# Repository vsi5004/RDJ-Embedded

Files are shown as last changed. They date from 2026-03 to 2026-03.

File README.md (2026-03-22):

# Vinyl Robot — EE & Firmware

Unified PCB design and STM32 firmware for a 5-node CANopen-based vinyl record handling robot.

## Documentation

- [System Architecture](docs/SYSTEM_ARCHITECTURE.md) — Mechanical overview, electrical architecture, safety layers
- [PCB Design](docs/PCB_DESIGN.md) — STM32G431 pin allocation, component selection, layout guidelines
- [Firmware Architecture](docs/FIRMWARE.md) — Bare-metal super-loop, CANopenNode integration, driver details
- [CANopen Protocol](docs/CANOPEN.md) — Object dictionary, PDO mapping, NMT lifecycle, bus analysis

## Hardware

- **MCU**: STM32G431CBU6 (UFQFPN48, 7×7mm)
- **Stepper driver**: TMC5160 stepstick (SPI motion controller mode)
- **CAN transceiver**: SN65HVD230
- **ToF sensors**: VL53L4CD (short range), VL53L1X (long range)
- **5 identical PCBs**, differentiated by populated components

## Development

Test-driven development with host-side unit tests (Unity framework, gcc). A HAL abstraction seam allows all driver and application logic to run on x86 with mock peripherals.

```bash
# Run all unit tests on host
make -C test/
```

See `docs/FIRMWARE.md` for the full TDD methodology, development phases, and HAL seam design.

## Prototyping

- Nucleo-G431RB for primary firmware development

## Related

ROS 2 control software lives in a separate repository. The CANopen object dictionary (EDS files) is the interface contract between firmware and ROS.

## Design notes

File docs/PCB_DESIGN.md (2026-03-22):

# PCB Design — Unified Controller Board

## MCU Selection

**STM32G431CBU6** (UFQFPN48, 7×7mm)

- Cortex-M4F @ 170MHz with FPU
- 128KB flash / 32KB RAM
- Native FDCAN peripheral
- 12-bit ADC with hardware 16× oversampling
- Multiple SPI, I2C, UART, timer peripherals
- Upgrade path: STM32G473CBU6 (same package, 256KB flash, 128KB RAM, pin-compatible)

### Why G431 over alternatives

- **vs STM32G0B1**: G0 has CAN-FD but Cortex-M0+ without FPU. ADC scaling and pot angle calculations benefit from FPU. Extra $2 is justified.
- **vs STM32F446**: G4 has native CAN-FD (not just CAN 2.0B) and better ADC oversampling.
- **vs RP2040**: No native CAN — would need external MCP2515 adding complexity and latency.
- **vs ESP32-S3**: TWAI (CAN 2.0B) works but FreeRTOS overhead is unnecessary for a dumb I/O node.

### Prototyping

Two Nucleo boards available:
- **Nucleo-G431RB** (LQFP64) — primary dev board, same silicon as G431CB
- **Nucleo-G474RE** (LQFP64) — backup/upgrade testing, 512KB flash

Pin remapping from Nucleo 64-pin to production 48-pin is a CubeMX regeneration — all peripherals in the allocation exist on both packages.

## Pin Allocation (21 of 37 usable GPIOs)

### SPI1 — TMC5160 Stepstick (4 pins)

| Pin | Function | Notes |
|-----|---|---|
| PA5 | SPI1_SCK | Stepstick clock |
| PA6 | SPI1_MISO | TMC5160 data out |
| PA7 | SPI1_MOSI | MCU data out |
| PA4 | SPI1_CS | Active low chip select |

The TMC5160 operates in full SPI motion controller mode. STEP/DIR pins on the stepstick are unused and remapped as REFL/REFR reference switch inputs. The optical endstop connects directly to the stepstick REFL pin — not to the MCU. StallGuard stop is enabled internally via the sg_stop bit in SWMODE. The EN pin on the stepstick header is tied permanently low (always enabled). Motor disable is done via SPI by writing TOFF=0 in CHOPCONF.

**This means the MCU's only connection to the stepper subsystem is 4 SPI pins.** Endstop, StallGuard, and enable are all handled by the TMC5160 internally. The MCU polls RAMPSTAT to learn about events after the fact.

### SPI2 — DotStar LEDs (2 pins)

| Pin | Function | Notes |
|-----|---|---|
| PB13 | SPI2_SCK | DotStar clock |
| PB15 | SPI2_MOSI | DotStar data (unidirectional) |

SPI2 is separate from SPI1 to avoid blocking TMC5160 reads during LED updates. DotStar frames are long (32 bits × up to 60 LEDs = 1920 bits) and would block SPI1 for ~50μs per update.

### FDCAN1 (2 pins)

| Pin | Function | Notes |
|-----|---|---|
| PA11 | FDCAN1_RX | From SN65HVD230 transceiver |
| PA12 | FDCAN1_TX | To SN65HVD230 transceiver |

### I2C1 — ToF Sensor (2 pins)

| Pin | Function | Notes |
|-----|---|---|
| PB8 | I2C1_SCL | 400kHz, 4.7kΩ pullups to 3.3V |
| PB9 | I2C1_SDA | VL53L4CD or VL53L1X at default 0x29 |

One ToF per board, one I2C bus per MCU — no address conflicts.

### TIM3 — RC Servo PWM (2 pins)

| Pin | Function | Notes |
|-----|---|---|
| PB4 | TIM3_CH1 | Servo 1 (grip/play) — 50Hz, 500–2500μs pulse |
| PB5 | TIM3_CH2 | Servo 2 (flip/speed) — 50Hz, 500–2500μs pulse |

On PB4/PB5 to avoid conflict with PA0 (ADC) on A axis board.

### ADC1 — Potentiometer (1 pin)

| Pin | Function | Notes |
|-----|---|---|
| PA0 | ADC1_IN1 | 10-turn pot, 16× hardware oversampling |

With 16× oversampling, effective resolution improves from 12-bit to ~16-bit. Over 300° of travel using ~8.3% of one turn, this gives approximately 0.05° effective resolution — adequate for the coarse homing application.

### USART2 — Debug UART (2 pins)

| Pin | Function | Notes |
|-----|---|---|
| PA2 | USART2_TX | Debug output, 115200 baud |
| PA3 | USART2_RX | Debug input |

Exposed on 3-pin JST-SH connector. Optional — can be omitted in production.

### SWD + Status (3 pins)

| Pin | Function | Notes |
|-----|---|---|
| PA13 | SWDIO | Tag-Connect TC2030 footprint |
| PA14 | SWCLK | Pogo-pin, no permanent connector |
| PB3 | GPIO out | Status LED — heartbeat toggle |

### Node ID DIP Switch (3 pins)

| Pin | Function | Notes |
|-----|---|---|
| PB0 | NODE_ID_0 | Internal pullup, switch to GND |
| PB1 | NODE_ID_1 | 3-bit = 8 addresses (5 used) |
| PB2 | NODE_ID_2 | Read once at boot |

PB0/PB1/PB2 are adjacent on the bottom edge of the LQFP48 package (pins 16/17/18), which is convenient for PCB routing.

PC13/PC14/PC15 are reserved for future use: PC14 (OSC32_IN) and PC15 (OSC32_OUT) for an optional LSE 32.768kHz crystal, and PC13 for RTC tamper/wakeup if an RTC is added. Neither is required by the current firmware — the IWDG uses the internal LSI and there is no RTC.

### Spare Pins (13 available)

PA1 (ADC — rail voltage monitoring), PA8 (TIM1 — buzzer), PA9/PA10 (USART1 — LiDAR passthrough if needed), PA15, PB6, PB7, PB10, PB11, PB12, PB14

## Population Matrix

| Component | X axis | Z axis | A axis | Pincher | Player |
|---|---|---|---|---|---|
| STM32G431CBU6 | ● | ● | ● | ● | ● |
| SN65HVD230 (CAN) | ● | ● | ● | ● | ● |
| 5V buck (3A) | ● | ● | ● | ● | ● |
| 3.3V LDO | ● | ● | ● | ● | ● |
| DIP switch (3-bit) | ● | ● | ● | ● | ● |
| TMC5160 stepstick socket | ● | ● | ● | ○ | ○ |
| Optical endstop connector | ● | ● | ● | ○ | ○ |
| ToF sensor connector (I2C) | ● | ● | ● | ● | ○ |
| Pot connector (ADC) | ○ | ○ | ● | ○ | ○ |
| Servo connectors (×2) | ○ | ○ | ○ | ● | ● |
| DotStar connector (SPI2) | ○ | ○ | ● | ○ | ● |
| 120Ω CAN termination jumper | ● | ○ | ○ | ○ | ● |

## PCB Layout Guidelines

- **Target board size**: ~50×40mm (similar to common stepper driver carriers)
- **Layers**: 2-layer, unbroken ground plane on bottom
- **Stepstick socket**: Standard 2×8 pin headers at 2.54mm pitch along one edge. Motor wires route away from signal traces.
- **Power entry**: 4-pin connector on one edge. 24V trace ≥1mm wide for 3A. Buck converter input/output caps close to IC.
- **CAN transceiver**: Between connector and MCU, near board edge. TVS diode (PESD2CAN) at connector pads.
- **Optional peripheral connectors**: JST-PH or JST-SH along remaining edges. 3-pin (VCC/GND/SIG) for simple sensors, 4-pin (VCC/GND/SCL/SDA) for I2C. Unpopulated variants leave connectors off.
- **SWD**: Tag-Connect TC2030 footprint (no permanent connector).
- **Do not let 24V trace split the ground plane.**

## Stepper Driver Selection

**TMC5160** in SPI motion controller mode (stepstick format).

The TMC5160's internal ramp generator handles all real-time step timing. The MCU sends target position, velocity, and acceleration parameters over SPI. The driver does the rest autonomously.

Key registers used:
- XTARGET: target position (written by MCU from CANopen RPDO)
- XACTUAL: current position (polled by MCU, reported in TPDO)
- VMAX, AMAX, DMAX: ramp parameters
- RAMPSTAT: status flags (position reached, stall detected, endstop hit)
- SWMODE: reference switch config (stop_l_enable for endstop, sg_stop for StallGuard)
- CHOPCONF: motor driver config (TOFF=0 to disable motor)
- SG_RESULT: StallGuard load measurement

### Stepstick compatibility note

Verify that the specific TMC5160 stepstick model remaps STEP/DIR pins as REFL/REFR when in SPI mode. Confirmed compatible: BTT TMC5160 V1.3, Watterott TMC5160 BOB. Some cheaper clones don't expose reference pins.

## Component Selection Summary

| Component | Part | Package | Notes |
|---|---|---|---|
| MCU | STM32G431CBU6 | UFQFPN48 | 128KB flash, M4F, FDCAN |
| CAN transceiver | SN65HVD230 | SOIC-8 | 3.3V, 1Mbit capable |
| CAN TVS | PESD2CAN | SOT-23 | Bidirectional TVS on CANH/CANL |
| 5V buck | MP2359 or TPS54331 | SOT-23-5/6 | 24V input, 3A output, for servos+LEDs |
| 3.3V LDO | AP2112K-3.3 | SOT-23-5 | 600mA, low dropout |
| ToF (short range) | VL53L4CD | module | 1–200mm, I2C, 18° FoV |
| ToF (long range) | VL53L1X | module | 4m max, I2C, programmable ROI |
| Status LED | 0603 green | 0603 | On PB3 via 470Ω |

## Flash Storage Layout

Last 4KB of 128KB flash reserved for persistent configuration:

| Address | Size | Purpose |
|---|---|---|
| 0x0801F000 | 2KB | Config slot A (active) |
| 0x0801F800 | 2KB | Config slot B (mirror) |

Double-buffer scheme: write new config to slot A, validate, then erase slot B. Next write goes to B, erase A. Atomic updates with power-loss protection. CANopenNode's OD_storage callback handles serialization.

Stored data per node: TMC5160 ramp defaults, StallGuard thresholds, pot calibration offset (A axis), node-specific config. ~256 bytes total. At 10,000 write cycle endurance, daily recalibration lasts 27 years.

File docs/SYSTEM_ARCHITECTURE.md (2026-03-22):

# Vinyl Robot — System Architecture

## Project Overview

An automated vinyl record handling robot that manages a queue of 5–6 records, picks them from a shelved stack, places them on a Pioneer PL-400 turntable, plays them, flips or swaps records, and returns them. The robot lives in a domestic living room environment with pets and humans nearby, requiring layered safety systems.

## Mechanical Architecture

The robot has a 1-meter linear stage (X axis) with two stations:
- **Left end (x=0)**: Shelved record queue stack — 5 slots with horizontal shelf floors between them, ~40mm pitch, ~20mm clearance per slot
- **Right end (x=1000mm)**: Pioneer PL-400 turntable connected to an audio system

### Axis Chain

**X axis (linear, 1000mm travel)** — Slides the entire upper assembly along a linear rail between the record stack and turntable. Driven by NEMA 17 stepper via TMC5160 in SPI motion controller mode.

**Z axis (vertical, ~150mm travel)** — Lead-screw driven vertical stage mounted on the X carriage. Lifts the end effector to clear the turntable platter and record stack shelves. Driven by NEMA 17 stepper via TMC5160.

**A axis (rotary, 300° travel)** — Belt-driven rotary stage mounted on the Z carriage. Rotates the pincher arm to reach records from different angles. Driven by NEMA 17 stepper via TMC5160. A 10-turn potentiometer provides coarse absolute position for safe homing on power-up. The pot is NOT used for closed-loop control — the TMC5160 microstep counter is the position authority during operation.

**Pincher (end effector)** — Two-jaw gripper that clamps a vinyl record from both sides. Driven by two RC servos: one for grip open/close, one for record flip (180° rotation). A VL53L4CD ToF sensor measures height above the surface below.

### Key Mechanical Constraints

- The record stack is a **shelved structure** with floors between slots. When the arm is inside a slot, Z movement is dangerous in both directions — shelves above and below with only ~20mm clearance.
- The A axis has physical hard stops at 0° and 300° to protect the cable wrap.
- The turntable is an open surface — Z up is always safe when near it.
- Furniture and walls constrain the A axis safe rotation window (configurable, default 30°–330°).

## Electrical Architecture

### Power Distribution

- **24V input** from a power supply in the robot base
- 24V rail routed through the full axis chain to each controller board
- Each board has:
  - 24V → TMC5160 VM (motor power) directly
  - 24V → 5V buck converter (3A, for servos and DotStar LEDs)
  - 5V → 3.3V LDO (MCU, CAN transceiver, sensors)

### CAN Bus

- Single CAN 2.0B bus at 1Mbit/s
- 5 nodes + SBC master
- 120Ω termination at both physical ends (X axis board and Player Control board) via solder jumpers
- SN65HVD230 transceivers on each node
- TVS protection (PESD2CAN) at each node's connector
- 4-pin connectors per board: 24V, GND, CANH, CANL

### Controller Boards

Five identical PCBs differentiated by populated components. See [PCB_DESIGN.md](./PCB_DESIGN.md) for full details.

| Node ID | Board | Populated Peripherals |
|---|---|---|
| 0x01 | X axis | TMC5160, endstop on stepstick, VL53L1X ToF |
| 0x02 | Z axis | TMC5160, endstop on stepstick, VL53L4CD ToF |
| 0x03 | A axis | TMC5160, endstop on stepstick, VL53L4CD ToF, 10-turn pot (ADC), DotStar ring (20 LEDs) |
| 0x04 | Pincher | 2× RC servos (grip + flip), VL53L4CD ToF |
| 0x05 | Player Control | 2× RC servos (play/stop + speed), DotStar strip (~1m, along X rail) |

### SBC (System on Module)

**Toradex Verdin iMX8M Plus (4GB RAM)** on **Mallow carrier board**

Selected for:
- Native dual CAN-FD (FlexCAN) — no USB adapter needed
- Gigabit Ethernet for SICK TIM571 LiDAR
- MIPI-CSI camera interface with ISP
- 2.3 TOPS NPU for future CV upgrades
- Industrial temp range and long-term availability
- Torizon OS with Docker-based ROS 2 deployment

### Sensors

**LiDAR**: SICK TIM571-2050101 (preferred) — 270° FoV, 15Hz, Ethernet TCP/IP. Mounted on top of Z column. Acts as a safety curtain.

**Camera**: USB or CSI camera for tonearm position tracking on the turntable. 640×480 @ 15fps is sufficient.

**ToF sensors**:
- X axis: VL53L1X (long range, 25mm–1000mm, focused beam via ROI) — startup collision avoidance
- Z axis: VL53L4CD (short range, 10–150mm, ±1mm) — height confirmation
- Pincher: VL53L4CD — height above surface below for grip confirmation
- All on I2C, one per board, no address conflicts

**Potentiometer**: 10-turn pot on A axis belt drive. Read via MCU ADC with 16× hardware oversampling. Used only for:
1. Coarse absolute angle on power-up (±2° accuracy, enough for safe homing direction)
2. Runtime sanity check against TMC5160 XACTUAL (every few seconds, ±5° divergence triggers EMCY)

## Safety Architecture (Layered)

| Layer | Mechanism | Response Time | Catches |
|---|---|---|---|
| 1 — Mechanical | Current limits on TMC5160, rubber bumpers, A axis hard stops | Instant | Force limits on all failures |
| 2 — StallGuard | TMC5160 sg_stop bit — driver stops motor internally | ~1ms | Collisions with objects, pets, humans |
| 3 — LiDAR | SICK TIM571 → ROS safety node → CAN halt | ~100ms | Humans approaching the robot |
| 4 — Watchdog | CAN heartbeat (100ms) + ROS lifecycle monitoring | 200–500ms | Software crashes, bus faults, node lockups |
| 5 — E-stop | Hardware power cut to 24V motor rail (relay/contactor) | Instant | Everything else |

## Software Architecture

### Firmware (this repo)

All five controller boards run the same firmware binary (STM32 bare-metal + CANopenNode). Behavior is selected by DIP switch node ID at boot. MCUs are dumb I/O nodes — no operational logic, no motion planning, no state machines. They receive commands and report status.

See [FIRMWARE.md](./FIRMWARE.md) and [CANOPEN.md](./CANOPEN.md) for details.

### ROS 2 (separate repo)

ROS 2 Humble on Torizon OS (Docker container). 7 nodes: CANopen master, motion coordinator, LiDAR safety, turntable monitor, state machine (BehaviorTree.CPP), LED controller, diagnostics.

All operational intelligence lives on the SBC. The SBC knows the mechanical geometry, safety zones, homing sequences, and the full record-handling workflow.

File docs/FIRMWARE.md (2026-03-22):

# Firmware Architecture

## Overview

All five controller boards run the same firmware binary. Behavior is selected by the 3-bit DIP switch (node ID) read at boot. The firmware is a bare-metal super-loop with CANopenNode as the communication stack. There is no RTOS. MCUs are dumb I/O nodes — they receive commands over CAN, actuate peripherals, read sensors, and report status. All operational intelligence lives on the SBC.

## Development Methodology — Test-Driven

All firmware modules are developed test-first. Unit tests run on the host machine (x86, gcc) without any target hardware. A thin HAL abstraction seam separates driver logic from STM32 register access. Driver code is identical on host and target — only the lowest-level HAL implementation differs.

**Test framework**: Unity (single-header C test framework). Mocks are hand-written — the HAL seam is thin enough that auto-generation (CMock) is unnecessary.

**Development cycle for each module**:
1. Write failing tests that define the expected behavior
2. Implement the driver/module to pass the tests
3. Run `make -C test/` to verify (builds and runs in under a second)
4. Flash to Nucleo for hardware validation

**Development phase order** (each builds on the previous):

| Phase | Tests | Module | Validates |
|---|---|---|---|
| 1 | Register r/w, target, status, StallGuard, init | `drv_tmc5160.c` | SPI protocol, bit packing, all register access |
| 2 | RPDO staging, SYNC application, TPDO latching, status word | `app_canopen.c` | Two-stage staging, atomic SYNC, status bits |
| 3 | Homing state machine, pot direction, endstop zero | `app_homing.c` | Per-axis homing, A axis pot logic |
| 4 | Fault detection, fault-blocks-motion, clear-fault, EMCY | fault paths in `app_canopen.c` | EMCY generation, status word, recovery |
| 5 | ToF ranging, servo clamping, DotStar framing | `drv_tof.c`, `drv_servo.c`, `drv_dotstar.c` | I2C protocol, PWM limits, LED format |
| 6 | Node config macros, flash roundtrip, corruption recovery | `node_config.h`, `cfg_flash.c` | Population logic, double-buffer integrity |

## Build System and Project Structure

Two build targets from the same source tree:
- **Target build**: arm-none-eabi-gcc / STM32CubeIDE — produces the binary for the STM32G431
- **Test build**: host gcc — compiles driver logic + mocks + Unity, runs on x86

```
firmware/
├── Core/                        # CubeMX generated HAL init (target only)
├── Drivers/                     # STM32 HAL + CMSIS (target only)
├── Lib/
│   └── CANopenNode/             # git submodule
├── App/
│   ├── hal/                     # Hardware abstraction seam
│   │   ├── hal_spi.h            # SPI interface (function pointer struct)
│   │   ├── hal_spi_stm32.c      # Real STM32 implementation (target only)
│   │   ├── hal_i2c.h
│   │   ├── hal_i2c_stm32.c
│   │   ├── hal_adc.h
│   │   ├── hal_adc_stm32.c
│   │   ├── hal_pwm.h
│   │   ├── hal_pwm_stm32.c
│   │   ├── hal_gpio.h
│   │   ├── hal_gpio_stm32.c
│   │   ├── hal_can.h
│   │   ├── hal_can_stm32.c
│   │   └── hal_flash.h
│   ├── drv/                     # Drivers — pure logic, testable on host
│   │   ├── drv_tmc5160.c        # SPI register r/w, ramp config, StallGuard
│   │   ├── drv_tmc5160.h
│   │   ├── drv_tof.c            # I2C ranging start/read (non-blocking)
│   │   ├── drv_tof.h
│   │   ├── drv_servo.c          # PWM pulse width control
│   │   ├── drv_servo.h
│   │   ├── drv_dotstar.c        # SPI2 LED frame output
│   │   └── drv_dotstar.h
│   ├── app/                     # Application logic — testable on host
│   │   ├── app_main.c           # Super-loop, boot sequence
│   │   ├── app_canopen.c        # OD definition, PDO callbacks, NMT hooks
│   │   ├── app_canopen.h
│   │   ├── app_homing.c         # Per-axis homing state machine
│   │   ├── app_homing.h
│   │   ├── cfg_flash.c          # Double-buffer flash config storage
│   │   └── node_config.h        # Node ID → peripheral enable mapping
│   └── OD/
│       ├── OD.h                 # Generated from EDS or hand-written
│       └── OD.c
├── test/                        # Host-side unit tests (x86, gcc)
│   ├── unity/                   # Unity test framework (vendored or submodule)
│   │   ├── unity.c
│   │   └── unity.h
│   ├── mocks/                   # Mock HAL implementations for testing
│   │   ├── mock_spi.c           # Records SPI writes, returns controlled data
│   │   ├── mock_spi.h
│   │   ├── mock_i2c.c
│   │   ├── mock_i2c.h
│   │   ├── mock_adc.c
│   │   ├── mock_adc.h
│   │   ├── mock_can.c
│   │   ├── mock_pwm.c
│   │   ├── mock_gpio.c
│   │   └── mock_flash.c
│   ├── test_tmc5160.c           # TMC5160 SPI driver tests
│   ├── test_canopen_pdo.c       # PDO staging + SYNC application tests
│   ├── test_homing.c            # Homing state machine tests
│   ├── test_fault.c             # Fault detection and EMCY tests
│   ├── test_tof.c               # ToF sensor I2C tests
│   ├── test_servo.c             # Servo PWM tests
│   ├── test_dotstar.c           # DotStar LED tests
│   ├── test_node_config.c       # Node ID mapping tests
│   ├── test_flash.c             # Flash double-buffer tests
│   └── Makefile                 # Builds and runs all tests on host
├── Makefile                     # Target build (arm-none-eabi-gcc)
└── vinyl_robot.ioc              # STM32CubeMX project
```

## HAL Abstraction Seam

The seam between testable logic and hardware is a struct of function pointers for each peripheral:

```c
// hal/hal_spi.h
typedef struct {
    int (*transfer)(uint8_t *tx, uint8_t *rx, uint16_t len);
} hal_spi_t;

extern hal_spi_t hal_spi1;  // Global instance — real or mock
```

On target, `hal_spi_stm32.c` sets the function pointer to the real STM32 HAL call. In tests, `mock_spi.c` provides a version that records what was transmitted and returns controlled responses.

Drivers accept the HAL instance at init and never include STM32 headers directly:

```c
// drv/drv_tmc5160.c
#include "drv_tmc5160.h"
#include "hal_spi.h"

static hal_spi_t *spi;

void tmc5160_init(hal_spi_t *spi_instance) {
    spi = spi_instance;
}

void tmc5160_write_register(uint8_t reg, uint32_t value) {
    uint8_t tx[5] = {
        reg | 0x80,
        (value >> 24) & 0xFF,
        (value >> 16) & 0xFF,
        (value >> 8) & 0xFF,
        value & 0xFF
    };
    uint8_t rx[5];
    spi->transfer(tx, rx, 5);
}
```

The `UNIT_TEST` preprocessor flag (set by the test Makefile, not by the target build) guards any remaining target-specific includes:

```c
#ifndef UNIT_TEST
#include "stm32g4xx_hal.h"
#endif
```

## Test Build

```bash
# Run all tests (from repo root)
make -C test/

# Run a single test suite
make -C test/ test_tmc5160 && test/test_tmc5160

# Clean
make -C test/ clean
```

The test Makefile compiles driver sources + mock HAL + Unity + test files with host gcc. Each test binary runs independently and exits with 0 on pass, non-zero on failure. Total test execution is under 1 second.

## Node Configuration

```c
// App/app/node_config.h
#define NODE_HAS_TMC(id)    ((id) >= 1 && (id) <= 3)
#define NODE_HAS_SERVO(id)  ((id) >= 4)
#define NODE_HAS_TOF(id)    ((id) != 5)
#define NODE_HAS_POT(id)    ((id) == 3)
#define NODE_HAS_LED(id)    ((id) == 3 || (id) == 5)
```

## Boot Sequence

```
1. HAL_Init() — clocks to 170MHz via HSI/PLL, SysTick
2. Read DIP switch (PC13/14/15) → node_id
3. Conditional peripheral init based on node_id:
   - if (node_id <= 0x03)  init_spi1_tmc5160();
   - if (node_id == 0x03)  init_adc_pot();
   - if (node_id == 0x03 || node_id == 0x05)  init_spi2_dotstar();
   - if (node_id >= 0x04)  init_pwm_servos();
   - if (node_id != 0x05)  init_i2c_tof();
4. load_config_from_flash(node_id);
5. CO_init() — start CANopenNode stack, enter NMT pre-operational
6. Start IWDG (100ms timeout)
7. Enter main super-loop
```

## Main Super-Loop

```c
while (1) {
    // 1. Service CANopen stack
    CO_process();  // NMT, SDO, heartbeat, emergency — ~5-20μs

    // 2. On SYNC callback (set by ISR flag)
    if (sync_received) {
        latch_tpdo_data();      // Copy sensor readings into TPDO buffers
        apply_queued_rpdo();    // Write staged commands to actuators
        sync_received = false;
    }

    // 3. TMC5160 polling (stepper nodes only)
    if (NODE_HAS_TMC(node_id)) {
        tmc5160_poll();  // Read XACTUAL, RAMPSTAT, SG_RESULT via SPI ~30μs
        if (rampstat_has_event()) {
            update_status_word();
            if (stallguard_triggered() || unexpected_endstop()) {
                send_emcy();
            }
        }
    }

    // 4. Sensor polling (10Hz, triggered by TIM7 flag)
    if (sensor_poll_flag) {
        if (NODE_HAS_TOF(node_id))  tof_read_distance();   // I2C ~100μs
        if (NODE_HAS_POT(node_id))  pot_read_angle();       // ADC register read
        if (NODE_HAS_LED(node_id))  dotstar_update();       // SPI2 if pattern changed
        sensor_poll_flag = false;
    }

    // 5. Servo update (servo nodes only)
    if (NODE_HAS_SERVO(node_id) && servo_target_changed) {
        servo_update_pwm();  // Write TIM3 CCR registers
        servo_target_changed = false;
    }

    // 6. Watchdog and diagnostics
    IWDG_kick();
    toggle_status_led();  // Heartbeat blink
    if (NODE_HAS_POT(node_id))  pot_sanity_check();  // Compare pot vs XACTUAL
}
```

Worst-case loop iteration: ~400μs → natural loop rate ~2.5kHz, well above 50Hz SYNC.

## Interrupt Context

Minimal — ISRs set flags, all heavy work in main loop.

| ISR | Handler | Purpose |
|-----|---|---|
| FDCAN1_IT0 | CO_CANinterrupt() | CAN frame reception, CANopenNode processing |
| SysTick | HAL_IncTick() + CO timing | 1ms tick for HAL delays and CANopenNode timers |
| TIM7 | Set sensor_poll_flag | 10Hz trigger for ToF/pot/LED polling |

**Design rule**: ISRs set flags only. All SPI, I2C, and CAN TX happen in the main loop. No peripheral bus access from ISR context.

## TMC5160 SPI Driver (App/drv/drv_tmc5160)

The driver communicates with the TMC5160 via SPI1 at 4MHz. All register access is 40-bit transactions (8-bit address + 32-bit data). The driver uses the `hal_spi_t` abstraction — it never touches STM32 HAL directly, making it fully testable on the host.

### Key Operations

```c
// Write a register
void tmc5160_write(uint8_t reg, uint32_t value);

// Read a register (returns 32-bit value, requires two transactions)
uint32_t tmc5160_read(uint8_t reg);

// Configure motion parameters
void tmc5160_set_target(int32_t position);   // Write XTARGET
void tmc5160_set_velocity(uint32_t vmax);    // Write VMAX
void tmc5160_set_accel(uint16_t amax, uint16_t dmax);  // Write AMAX, DMAX
void tmc5160_set_rampmode(uint8_t mode);     // 0=position, 1=velocity+, 2=velocity-

// Read status
int32_t tmc5160_get_position(void);          // Read XACTUAL
uint32_t tmc5160_get_rampstat(void);         // Read RAMPSTAT
uint16_t tmc5160_get_stallguard(void);       // Read SG_RESULT

// Motor control
void tmc5160_disable(void);  // Write TOFF=0 in CHOPCONF
void tmc5160_enable(void);   // Restore TOFF from config
```

### Initialization Sequence

```c
void tmc5160_init(void) {
    // 1. Write GCONF — enable SPI mode, internal ramp generator
    // 2. Write CHOPCONF — set TOFF, HSTRT, HEND for motor tuning
    // 3. Write IHOLD_IRUN — set run current, hold current, hold delay
    // 4. Write SWMODE — enable stop_l_enable (endstop), sg_stop (StallGuard)
    // 5. Write SGTHRS — StallGuard threshold (from flash config)
    // 6. Write VMAX, AMAX, DMAX — default ramp parameters (from flash config)
    // 7. Write RAMPMODE = 0 — position mode
    // 8. Write XACTUAL = 0 — assume unhomed
}
```

### Homing (Stepper Nodes)

Homing is initiated by the SBC setting the "home" bit in the control word (OD 0x2004). The MCU runs the homing sequence locally:

**X and Z axes:**
1. Set TMC5160 to velocity mode at slow speed, toward endstop
2. TMC5160 hits endstop on REFL → stops internally (SWMODE stop_l_enable)
3. MCU reads XACTUAL, writes it to zero
4. Set status word "homed" bit
5. Return to position mode

**A axis:**
1. Read pot via ADC → determine which direction is shortest path to endstop
2. Set TMC5160 to velocity mode toward endstop in that direction
3. TMC5160 hits endstop → stops
4. Zero XACTUAL
5. Set "homed" bit

The SBC orchestrates the ORDER of homing (which axis homes first, moving to safe zones between steps). But the actual endstop-seek-and-zero on each individual axis is handled by the MCU firmware.

## RPDO/TPDO Callback Pattern

CANopenNode uses callbacks for OD entry writes. The firmware implements a two-stage staging pattern:

1. **RPDO write callback**: Copy received value into a shadow buffer. Set "pending" flag. Do NOT actuate yet.
2. **SYNC callback**: If pending flag is set, copy shadow buffer to live target. Execute actuation (SPI write to TMC5160, or PWM update for servos). Clear pending flag.

This ensures:
- Multi-field commands (target + velocity + accel) all apply atomically on the same SYNC
- No partial updates if the master sends fields across multiple CAN frames
- SYNC-gated start for coordinated multi-axis moves

## Fault Handling

When a fault is detected (StallGuard, unexpected endstop, sensor timeout, SPI failure):

1. Set fault bit in status word (OD 0x2003)
2. Send CANopen EMCY frame with error code
3. Hold current position (don't disable motor — maintain holding torque)
4. Ignore new motion commands until fault is cleared
5. Wait for SBC to send clear-fault via control word (OD 0x2004)

### EMCY Error Codes

| Code | Meaning |
|---|---|
| 0x2100 | StallGuard triggered |
| 0x2200 | Unexpected endstop hit (not during homing) |
| 0x2300 | ToF reading out of expected range |
| 0x2400 | Pot vs XACTUAL divergence exceeds 5° (A axis) |
| 0x2500 | TMC5160 SPI communication failure |
| 0x2600 | Servo position feedback timeout |
| 0x5000 | CAN bus-off recovery |

## FDCAN Configuration

CAN 2.0B (classic CAN) at 1Mbit/s with 170MHz PCLK1:

- Prescaler: 10
- Time segment 1: 13
- Time segment 2: 3
- Sync jump width: 1
- → 17 time quanta per bit, 76.5% sample point

Two RX filters:
1. Accept standard frames matching node ID range (SDO, NMT directed)
2. Accept broadcast frames (SYNC, NMT broadcast, emergency)

## Development Notes

### Getting CANopenNode Running First

Before adding any motion code, get the CANopen stack running in isolation:
1. Init FDCAN with correct bit timing
2. Init CANopenNode with minimal OD (just mandatory objects)
3. Verify heartbeat visible on CAN bus (use Nucleo + CAN transceiver breakout)
4. Test SDO read/write of a single OD entry from a second Nucleo or PC with CAN adapter
5. Then add TMC5160 SPI driver, sensors, etc. incrementally

FDCAN filter configuration and timing register setup are the most common gotchas on STM32G4.

### StallGuard Tuning

StallGuard sensitivity needs different thresholds for:
- **Homing**: Very sensitive (high SGTHRS) — moving slowly with no load, any resistance = obstacle
- **Normal operation**: Less sensitive — carrying a record adds load, shouldn't false-trigger
- **Near turntable**: May need adjusted sensitivity due to different friction characteristics

Log SG_RESULT values during normal operations to find the threshold window. Store per-node thresholds in flash config. The SBC can adjust via SDO during operation if needed.

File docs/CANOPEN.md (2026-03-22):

# CANopen Protocol Specification

## Network Configuration

- **Bus speed**: 1Mbit/s CAN 2.0B (classic CAN, not CAN-FD)
- **SYNC period**: 20ms (50Hz), broadcast by SBC master
- **Heartbeat producer**: 100ms interval on all nodes
- **Heartbeat consumer**: SBC detects node loss within 200ms (2 missed heartbeats)
- **SDO timeout**: 500ms
- **Termination**: 120Ω at node 0x01 (X axis) and node 0x05 (Player) — solder jumper on PCB

## Node Addressing

| Node ID | Board | DIP Switch | CAN ID Range (hex) |
|---|---|---|---|
| 0x01 | X axis | 001 | TPDO: 0x181, RPDO: 0x201, SDO TX: 0x581, SDO RX: 0x601 |
| 0x02 | Z axis | 010 | TPDO: 0x182, RPDO: 0x202, SDO TX: 0x582, SDO RX: 0x602 |
| 0x03 | A axis | 011 | TPDO: 0x183, RPDO: 0x203, SDO TX: 0x583, SDO RX: 0x603 |
| 0x04 | Pincher | 100 | TPDO: 0x284, RPDO: 0x304, SDO TX: 0x584, SDO RX: 0x604 |
| 0x05 | Player | 101 | TPDO: 0x285, RPDO: 0x305, SDO TX: 0x585, SDO RX: 0x605 |

SYNC COB-ID: 0x080 (broadcast)
NMT COB-ID: 0x000 (broadcast)
Heartbeat COB-ID: 0x700 + node_id

## Object Dictionary

### Mandatory CANopen Objects (all nodes)

| Index | Sub | Type | Name | Default |
|---|-----|---|---|---|
| 0x1000 | 0 | UINT32 | Device type | 0x000F0191 |
| 0x1001 | 0 | UINT8 | Error register | 0x00 |
| 0x1017 | 0 | UINT16 | Producer heartbeat time (ms) | 100 |
| 0x1018 | 1 | UINT32 | Vendor ID | TBD |
| 0x1018 | 2 | UINT32 | Product code | TBD |
| 0x1018 | 3 | UINT32 | Revision number | firmware version |

### Common Application Objects (all nodes)

| Index | Sub | Type | Name | Access | Notes |
|---|-----|---|---|---|---|
| 0x2000 | 0 | UINT8 | Node role | RO | Read from DIP switch at boot |
| 0x2001 | 0 | UINT16 | Firmware version | RO | Major.minor packed |
| 0x2002 | 0 | UINT16 | Board temperature | RO | Internal ADC, °C × 10 |
| 0x2003 | 0 | UINT8 | Status word | RO | See bit definitions below |
| 0x2004 | 0 | UINT8 | Control word | RW | See bit definitions below |
| 0x2005 | 0 | UINT32 | Uptime (ms) | RO | Since boot |

#### Status Word (0x2003) Bit Definitions

| Bit | Name | Description |
|-----|---|---|
| 0 | homed | Axis has been homed since boot |
| 1 | moving | Ramp generator is active (RAMPSTAT velocity ≠ 0) |
| 2 | in_position | Target position reached (RAMPSTAT position_reached) |
| 3 | fault | Fault active — motion commands ignored |
| 4 | homing | Currently executing homing sequence |
| 5 | stallguard_active | StallGuard monitoring enabled |
| 6–7 | reserved | |

#### Control Word (0x2004) Bit Definitions

| Bit | Name | Description |
|-----|---|---|
| 0 | enable | Enable motor driver (write TOFF in CHOPCONF) |
| 1 | home | Start homing sequence |
| 2 | halt | Emergency halt — decelerate to stop |
| 3 | clear_fault | Clear fault state, resume normal operation |
| 4–7 | reserved | |

### Motion Objects — Stepper Nodes (0x01, 0x02, 0x03)

| Index | Sub | Type | Name | Access | Notes |
|---|-----|---|---|---|---|
| 0x2100 | 0 | INT32 | Target position | RW | Microsteps → TMC5160 XTARGET |
| 0x2101 | 0 | INT32 | Actual position | RO | TMC5160 XACTUAL |
| 0x2102 | 0 | UINT32 | Max velocity (pps) | RW | → TMC5160 VMAX |
| 0x2103 | 0 | UINT16 | Acceleration | RW | → TMC5160 AMAX |
| 0x2104 | 0 | UINT16 | Deceleration | RW | → TMC5160 DMAX |
| 0x2105 | 0 | UINT8 | Ramp status | RO | TMC5160 RAMPSTAT bits |
| 0x2106 | 0 | UINT16 | StallGuard result | RO | TMC5160 SG_RESULT |
| 0x2107 | 0 | UINT16 | ToF distance (mm) | RO | VL53L reading |
| 0x2108 | 0 | UINT8 | Ramp mode | RW | 0=position, 1=velocity+, 2=velocity- |

### A Axis Extras (node 0x03 only)

| Index | Sub | Type | Name | Access | Notes |
|---|-----|---|---|---|---|
| 0x2200 | 0 | INT16 | Pot angle (0.1° units) | RO | Coarse absolute — homing + sanity check |
| 0x2220 | 0 | UINT32 | LED pattern | RW | DotStar ring state |

### Servo Objects — Pincher (0x04) and Player (0x05)

| Index | Sub | Type | Name | Access | Notes |
|---|-----|---|---|---|---|
| 0x2300 | 0 | UINT16 | Servo 1 position (μs) | RW | Pulse width 500–2500μs |
| 0x2301 | 0 | UINT16 | Servo 2 position (μs) | RW | Pulse width 500–2500μs |
| 0x2302 | 0 | UINT16 | ToF distance (mm) | RO | Pincher only |
| 0x2310 | 0 | UINT32 | LED pattern | RW | Player only (X rail strip) |

## PDO Mapping

### TPDO1 — Stepper Nodes (on SYNC, 50Hz)

Transmits actual position, status, and sensor data every SYNC cycle.

| Byte(s) | OD Index | Type | Content |
|---|---|---|---|
| 0–3 | 0x2101 | INT32 | Actual position (XACTUAL) |
| 4 | 0x2003 | UINT8 | Status word |
| 5 | 0x2105 | UINT8 | Ramp status |
| 6–7 | 0x2107 | UINT16 | ToF distance (mm) |

Total: 8 bytes (maximum CAN payload)

### TPDO1 — Servo Nodes (on SYNC, 50Hz)

| Byte(s) | OD Index | Type | Content |
|---|---|---|---|
| 0–1 | 0x2300 | UINT16 | Servo 1 actual position |
| 2–3 | 0x2301 | UINT16 | Servo 2 actual position |
| 4–5 | 0x2302 | UINT16 | ToF distance (Pincher) or 0 |
| 6 | 0x2003 | UINT8 | Status word |

Total: 7 bytes

### RPDO1 — Stepper Nodes (event-driven from master)

| Byte(s) | OD Index | Type | Content |
|---|---|---|---|
| 0–3 | 0x2100 | INT32 | Target position (microsteps) |
| 4–5 | 0x2102 | UINT16 | Max velocity (scaled) |
| 6 | 0x2004 | UINT8 | Control word |
| 7 | 0x2108 | UINT8 | Ramp mode |

Total: 8 bytes

### RPDO1 — Servo Nodes (event-driven from master)

| Byte(s) | OD Index | Type | Content |
|---|---|---|---|
| 0–1 | 0x2300 | UINT16 | Servo 1 target |
| 2–3 | 0x2301 | UINT16 | Servo 2 target |
| 4–7 | 0x2310/0x2004 | UINT32/UINT8 | LED pattern (Player) or control word (Pincher) |

Total: 8 bytes

## SYNC-Gated Motion Coordination

For simultaneous multi-axis moves:

1. SBC writes RPDO to X axis (target + velocity + accel) — staged, not applied
2. SBC writes RPDO to Z axis — staged
3. SBC writes RPDO to A axis — staged
4. SBC broadcasts SYNC frame
5. All nodes' SYNC callback fires → apply staged RPDO → write to TMC5160
6. All axes start ramps within one CAN frame period (~130μs) of each other

## NMT Lifecycle

```
INITIALIZING → PRE-OPERATIONAL → OPERATIONAL → STOPPED
                                       ↑            ↓
                                       └── (clear fault) ←┘
```

- **INITIALIZING**: Boot + hardware init. Automatic transition to PRE-OPERATIONAL.
- **PRE-OPERATIONAL**: SDO configuration accessible. No PDO exchange. SBC can read/write OD entries to configure node before going operational.
- **OPERATIONAL**: PDOs active. Full real-time data exchange. Normal operating state.
- **STOPPED**: Entered on fault or SBC command. No PDO exchange. Node holds position.

SBC waits for heartbeats from all 5 nodes in PRE-OPERATIONAL, then sends NMT "start all" to transition to OPERATIONAL.

## CAN Bus Bandwidth Analysis

At 50Hz SYNC with all 5 nodes active, worst case per cycle:

| Frame Type | Count | Bytes | Bits on Wire |
|---|---|---|---|
| SYNC | 1 | 0 | ~50 |
| TPDO1 (stepper ×3) | 3 | 8 each | 390 |
| TPDO1 (servo ×2) | 2 | 7 each | 260 |
| RPDO1 (stepper ×3) | 3 | 8 each | 390 |
| RPDO1 (servo ×2) | 2 | 8 each | 260 |
| Heartbeats | ~2.5/cycle | 1 each | 125 |

Total: ~1,475 bits per 20ms cycle = 73.75 kbit/s = **7.4% bus utilization at 1Mbit**

Ample headroom for SDO traffic, EMCY frames, and occasional diagnostic reads.

## EDS File Structure

Three EDS files needed for `ros2_canopen` configuration:

- **stepper_node.eds**: Shared by X (0x01) and Z (0x02). Motion objects 0x2100–0x2108.
- **a_axis_node.eds**: Same as stepper_node plus pot (0x2200) and DotStar (0x2220).
- **servo_node.eds**: Shared by Pincher (0x04) and Player (0x05). Servo objects 0x2300–0x2310.

## CANopenNode Integration Notes

- Use CANopenNode C library (not Lely, which is heavier)
- STM32G4 FDCAN driver available in `CANopenNode/driver/STM32/`
- Register SYNC callback via `CO_SYNC_initCallbackPre()` — fires from CAN RX interrupt
- OD storage callback for flash persistence: point at reserved flash pages
- Configure FDCAN filters: one for node-specific frames, one for broadcast
- EMCY producer: call `CO_errorReport()` to send emergency frames

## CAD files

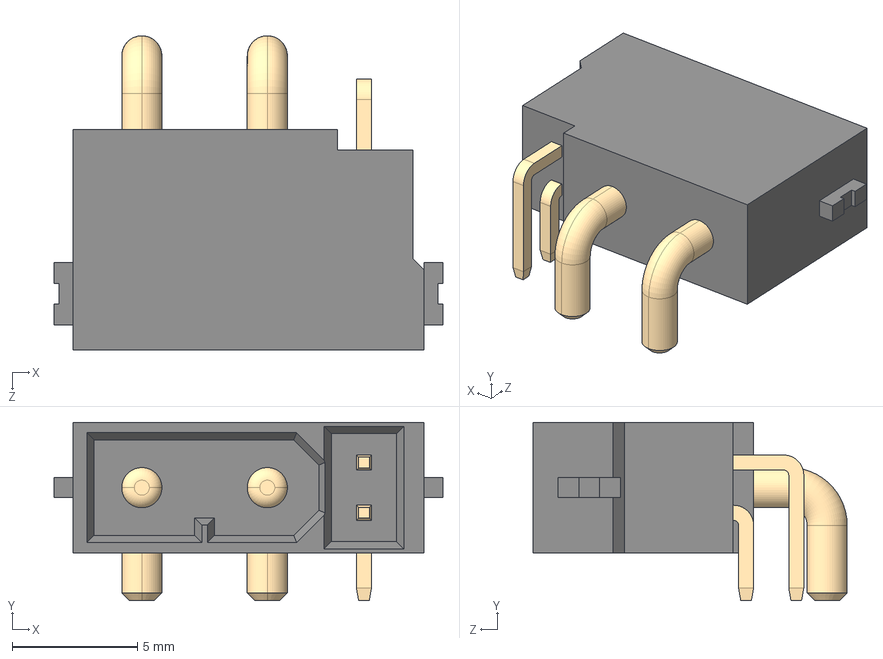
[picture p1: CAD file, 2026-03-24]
PCB/Components/XT30PW_2_2_-M.G.B.step
15.5 x 7.10 x 12.5 mm

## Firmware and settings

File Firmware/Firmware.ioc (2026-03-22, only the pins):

Mcu.UserName=STM32G431RBTx
PA0.Signal=ADC1_IN1
PA11.Signal=FDCAN1_RX
PA12.Signal=FDCAN1_TX
PA13.GPIO_Label=T_SWDIO
PA13.Signal=SYS_JTMS-SWDIO
PA14.GPIO_Label=T_SWCLK
PA14.Signal=SYS_JTCK-SWCLK
PA2.Signal=USART2_TX
PA3.Signal=USART2_RX
PA4.GPIO_Label=SPI1_CS
PA4.Signal=GPIO_Output
PA5.Signal=SPI1_SCK
PA6.Signal=SPI1_MISO
PA7.Signal=SPI1_MOSI
PB0.GPIO_Label=NODE_ID_0
PB0.Signal=GPIO_Input
PB1.GPIO_Label=NODE_ID_1
PB1.Signal=GPIO_Input
PB13.Signal=SPI2_SCK
PB15.Signal=SPI2_MOSI
PB2.GPIO_Label=NODE_ID_2
PB2.Signal=GPIO_Input
PB3.GPIO_Label=STATUS_LED
PB3.Signal=GPIO_Output
PB4.Signal=S_TIM3_CH1
PB5.Signal=S_TIM3_CH2
PB8-BOOT0.Signal=I2C1_SCL
PB9.Signal=I2C1_SDA
PC14-OSC32_IN.GPIO_Label=RCC_OSC32_OUT
PC14-OSC32_IN.Signal=RCC_OSC32_IN
PC15-OSC32_OUT.GPIO_Label=RCC_OSC32_OUT
PC15-OSC32_OUT.Signal=RCC_OSC32_OUT
PF0-OSC_IN.GPIO_Label=RCC_OSC_IN
PF0-OSC_IN.Signal=RCC_OSC_IN
PF1-OSC_OUT.GPIO_Label=RCC_OSC_OUT
PF1-OSC_OUT.Signal=RCC_OSC_OUT

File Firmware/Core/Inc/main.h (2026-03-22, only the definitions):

#define RCC_OSC32_OUT_Pin GPIO_PIN_14
#define RCC_OSC32_OUT_GPIO_Port GPIOC
#define RCC_OSC32_OUTC15_Pin GPIO_PIN_15
#define RCC_OSC32_OUTC15_GPIO_Port GPIOC
#define RCC_OSC_IN_Pin GPIO_PIN_0
#define RCC_OSC_IN_GPIO_Port GPIOF
#define RCC_OSC_OUT_Pin GPIO_PIN_1
#define RCC_OSC_OUT_GPIO_Port GPIOF
#define SPI1_CS_Pin GPIO_PIN_4
#define SPI1_CS_GPIO_Port GPIOA
#define NODE_ID_0_Pin GPIO_PIN_0
#define NODE_ID_0_GPIO_Port GPIOB
#define NODE_ID_1_Pin GPIO_PIN_1
#define NODE_ID_1_GPIO_Port GPIOB
#define NODE_ID_2_Pin GPIO_PIN_2
#define NODE_ID_2_GPIO_Port GPIOB
#define T_SWDIO_Pin GPIO_PIN_13
#define T_SWDIO_GPIO_Port GPIOA
#define T_SWCLK_Pin GPIO_PIN_14
#define T_SWCLK_GPIO_Port GPIOA
#define STATUS_LED_Pin GPIO_PIN_3
#define STATUS_LED_GPIO_Port GPIOB

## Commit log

2026-03-22 Initial commit: CubeMX HAL, HAL seam, TMC5160 driver, test infrastructure
    - STM32CubeMX generated project for STM32G431CBU6 (SPI1/2, I2C1, FDCAN1,
    ADC1, TIM3/7, USART2, IWDG) targeting Nucleo-G431RB
    - HAL abstraction seam (hal_spi/i2c/adc/pwm/gpio/can) with STM32 bindings
    - Phase 1: drv_tmc5160 — SPI register access, ramp config, StallGuard,
    enable/disable; 24 passing host-side unit tests
    - Test infrastructure: Unity (vendored), mock HAL implementations,
    host Makefile with auto Unity download
    - GitHub Actions CI: builds and runs all test suites on ubuntu-latest
    [Firmware.ioc, drv_tmc5160.c]
2026-03-22 Report real suite elapsed time in JUnit XML
    Measure wall-clock time around each test binary with date +%s%3N
    (millisecond precision) and pass it to unity_to_junit.py, which
    formats it as seconds on the <testsuite time=""> attribute.
    Per-test time remains 0 since Unity does not report it.
2026-03-22 Phase 2: CANopen PDO staging, SYNC application, status word
    Adds app_canopen module implementing the two-stage RPDO staging pattern:
    values are buffered on RPDO receive and applied atomically on SYNC, ensuring
    coordinated multi-axis motion starts within one CAN frame period.
    - app_canopen.h/c: RPDO shadow buffer, SYNC processor, TPDO latch,
    status word API (set/clear bits), ToF distance injection
    - test_canopen_pdo.c: 27 tests covering staging, SYNC application,
    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
2026-03-22 Phase 3: Homing state machine
    Adds app_homing module implementing the single-axis seek-and-zero sequence.
    The same state machine is used by all three stepper nodes (X, Z, A) — the
    SBC is responsible for deciding when it is safe to home each axis.
    - app_homing.h/c: start() writes TMC5160 to VEL_NEG mode at seek velocity;
    tick() polls RAMPSTAT each super-loop iteration; on EVENT_STOP_L zeroes
    XACTUAL, restores position mode, sets HOMED, clears HOMING
    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
2026-03-22 Add Phase 4: fault detection, EMCY generation, and motion blocking
    - canopen_bind_can(): bind CAN HAL instance and node ID for EMCY TX
    - canopen_report_fault(): sets FAULT status bit and transmits CANopen
    EMCY frame (error code LE, error register 0x01, 8 bytes, COB-ID 0x80+node)
    - canopen_sync_process(): motion commands (XTARGET/VMAX/RAMPMODE) are
    blocked while FAULT bit is set; CTRL_CLEAR_FAULT unblocks on same SYNC
    - 14 new tests in test_fault.c: EMCY frame contents, fault-blocks-motion,
    TPDO still latches during fault, clear-fault recovery, distinct error codes
    [app_canopen.c, test_fault.c]
2026-03-22 Add Phase 5: ToF, servo, and DotStar drivers with tests
    drv_tof (VL53L4CD / VL53L1X, I2C):
    - 16-bit register addressing (MSB-first)
    - start_ranging() writes SYSTEM__START 0x0087 = 0x40
    - is_data_ready() polls GPIO__TIO_HV_STATUS 0x0031 bit 0
    - get_distance_mm() reads 2-byte big-endian result from 0x0096
    - clear_interrupt() writes 0x01 to SYSTEM__INTERRUPT_CLEAR 0x0086
    drv_servo (RC servo, PWM):
    - Clamps pulse width to [500, 2500] μs before HAL call
    - Out-of-range requests silently clamped (protects against SBC errors)
    drv_dotstar (APA102 LEDs, SPI):
    - Frame: 4×0x00 start | [0xE0|bright5, B, G, R] per LED | 4×0xFF end
    - Brightness masked to 5 bits; colour wire order is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
    [drv_dotstar.c, drv_tof.c, test_dotstar.c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]
2026-03-22 Add Phase 6: node config macros and double-buffer flash storage
    node_config.h — NODE_HAS_* macros mapping node ID (1-5) to populated
    peripherals (TMC/Servo/ToF/Pot/LED); 25 tests verify the full matrix
    cfg_flash.c — power-loss-safe double-buffer config persistence:
    - node_config_t: vmax/amax/dmax/sgt/pot_offset + magic + seq + checksum
    - cfg_flash_save(): writes to inactive slot, increments seq, erases old slot
    - cfg_flash_load(): picks valid slot with highest seq; falls back to defaults
    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
2026-03-22 Refactor for maintainability; clean up phase-number comments
    Implementation:
    - cfg_flash: extract find_active_slot() so the slot-selection logic
    lives in one place instead of being duplicated between load and save
    - drv_dotstar: replace four parallel arrays with a dotstar_pixel_t
    struct array; groups related per-LED data and makes set_pixel a
    single assignment
    - drv_tmc5160: improve comments on the two-transaction read protocol;
    remove redundant second tx[0] assignment
    Docs / comments:
    - Remove "Phase N —" prefixes from all test file headers and the
    FIRMWARE.md file tree; they described development order but add no
    value to future readers
    - Fix pre-existing FIRMWARE.md inaccur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
    [drv_dotstar.c, drv_tmc5160.c, test_canopen_pdo.c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]
2026-03-22 Add firmware build CI workflow
    Builds the STM32G431 firmware with release flags (DEBUG=0, OPT=-O2)
    and uploads .elf/.hex/.bin as artefacts, ready to attach to future releases.
2026-03-24 Add DMAX factor scaling and PCB design files
    - app_canopen: decode RPDO byte 7 bits [7:2] as dmax_factor for
    per-waypoint deceleration scaling (position mode only)
    - app_canopen: add canopen_set_cfg_dmax() to store configured DMAX
    - test_canopen_pdo: 5 new tests for DMAX factor (zero, scale, clamp,
    velocity skip, bitfield extraction)
    - PCB: add KiCad schematic, PCB layout, and XT30PW component library
    - .gitignore: exclude KiCad backups and .history
    [RDJController.kicad_pcb, RDJController.kicad_sch, XT30PW_2_2_-M.G.B.step]

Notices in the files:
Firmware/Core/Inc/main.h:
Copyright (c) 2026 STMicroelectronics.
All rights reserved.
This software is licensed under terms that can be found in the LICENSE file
